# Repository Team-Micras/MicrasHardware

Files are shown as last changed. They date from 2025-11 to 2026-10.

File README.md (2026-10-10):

# Micras chassis

A parametric chassis for the Micras micromouse, written as [build123d](https://github.com/gumyr/build123d) code. Every dimension lives in `micras/params.py` and in the `*Params` dataclasses at the top of each part module. Change a value, then rerun the checks and the exports.

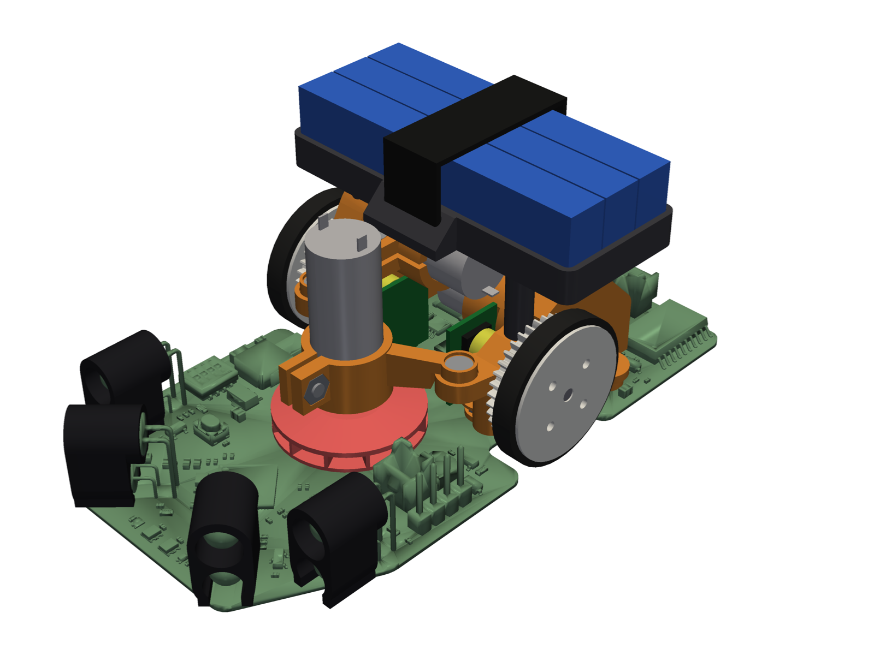
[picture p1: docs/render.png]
The robot: main board, sensor caps, fan, drive blocks, wheels and battery basket


The previous design (SolidWorks parts and assembly) was removed from the tree; it is in the git history (`git show 1307880:MicrasAssembly.STEP`).

## Workflow

```sh
uv sync                                   # Python 3.12 environment
uv run tools/export_board.py              # re-import the board after it changes in ../hw_debug (needs Windows KiCad); the wall sensors get the datasheet LED models of micras/leds.py (--original-sensors keeps the embedded model)
uv run pytest -q                          # design rules: clashes, board contact zones, LED fit, CoM over the axle
uv run tools/show.py                      # send the model to the OCP CAD Viewer, grouped, with the real board and its silkscreen (--simple: boxes)
uv run tools/render.py out.png --view iso --extra micras.assembly:printed          # the README's render (docs/render.png)
uv run tools/render.py out.png --dir=0.5,1,0.75 --focus=-5,13,14 --zoom 3 --extra micras.assembly:printed \
    --hide cell,velcro,sensor_cap --ghost block,fan_mount,basket,wheel,magnet_cup,impeller,tire   # docs/render_inside.png
uv run tools/export.py                    # build/print/<group>/*.stl (turned to print), build/print/parts.md, build/micras.step, build/skirt.dxf|svg, build/skirt_sheet.svg|pdf|png
uv run python -m micras.skirt             # the skirt files alone (seconds): build/skirt.dxf|svg and the cutting sheet
uv run tools/slice.py [plate ...]         # build/sliced/*.pm4n (Photon Mono 4) and *.gcode (Ender 3 V3 SE); see docs/printing.md
uv run tools/mass_report.py               # mass, centre of mass, yaw inertia, battery position for balance
uv run tools/battery_study.py             # compare battery arrangements
uv run tools/check_gears.py [--png f]    # the printed wheel with the brass pinion (the robot), and the all-printed pair: mesh through a tooth pitch, backlash, binding distance, tooth stress
uv run tools/fea.py [part ...] [--png]    # structural check of the printed parts (about 13 min for all, 1-3 min per part)
```

Run heavy jobs through `tools/capped.sh`, for example `tools/capped.sh uv run tools/export.py`. It caps memory at 6 GB so that a runaway job gets killed instead of crashing WSL.

**Structural check.** `tools/fea.py` meshes each printed part with gmsh and solves linear elasticity with scikit-fem (quadratic tets, pyamg solver) under rough worst-case loads: a 1 m/s crash into a wall (100 g), a 30 cm drop onto the wheels (300 g), side hits, handling pushes and the impeller's spin. It reports the stress exceeded in only 0.1 % of the volume (the raw peak sits in sharp corners, where linear FEA does not converge) against printed-material strengths (resin 35 MPa; PLA 37 MPa along its layers and 15 MPa across them, using the print orientation; TPU 8.6 MPa), and flags anything under a safety factor of 2 (3 for sustained loads). A flag means "look here": the loads are estimates. It runs on the CPU (about 5 GB at most); run it through `tools/capped.sh` with `MEM=5G`. `--dry` only meshes the parts and checks that every support and load finds its faces (seconds).

**Robot frame.** The same frame as the firmware: the origin is on the floor under the midpoint of the wheel axle, x points forward, y points left and z points up, in millimetres.

## Parts

| Module | Parts | Material |
|---|---|---|
| `drive.py` | bearing blocks (base + cap per side, or one piece) with the outer bearing's tube, magnet cups, wheels (gear, drum and end web in one piece) | resin |
| `fan.py` | closed radial impeller (Ø22, eye 10, 12 blades, neck into the board hole); the fan mount, a yoke hung from the drive caps with a split collar clamp | resin |
| `frame.py` | battery basket on two posts onto the drive caps, held shut by a velcro strap | PLA |
| `leds.py` | SFH 4550 and TPS601A models from their datasheets (they replace the board model's hand-drawn LEDs) and the numbers the caps are built from | – |
| `gears.py` | printed gears (0.5M 7T pinion, the 36T gear of the wheel), generated with py_gearworks; the robot uses the wheel gear with the brass pinion (`Gears.wheel_gear = "printed"`) | resin |
| `gear_guide.py` | drill guide for the brass 36T (the alternative): its bore opened to Ø7.8 and three Ø2.2 holes on Ø12.3 | resin |
| `trials.py` | trial parts on a plate of their own (`build/print/trials`), the default design untouched: impellers for a fan motor with a plain Ø1.5 shaft (bores 1.55 and 1.58, one or two dots), the tire cutting guide (a post and a turning ring with a blade slit at the channel's width), and wheel pairs with 0.20, 0.16, 0.12 and 0.08 mm of backlash with the brass pinion (the value engraved on the gear's inboard face, in hundredths) | resin |
| `front.py` | four wall-sensor caps that stand on the footprint outlines and set the LEDs' aim | black PLA |
| `skirt.py`, `skirt_sheet.py` | skirt and nose doubler patterns, and a 1:1 cutting sheet with rulers and a bank-card outline to trace them from a screen | film: 10 µm polyethylene, 40 µm cellulose acetate or TPU, chosen by measured downforce |
| `skirt_guide.py` | the skirt's cutting templates (a ring and a nose piece in the skirt's and the doubler's shapes: the scalpel runs along their walls) and its placing jig (an island under the band, a fence at the lip's edge, two pins in the board's screw holes) | resin |
| `fasteners.py` | the M2 screws, nuts and inserts in place, from the same helpers that cut their holes (viewer, STEP, `check_layout.py`) | bought |
| `skids.py` | where the two PTFE skates go under the board's centre line, front and rear, and their size | bought (mouse skates) |

`build/parts.md` lists each part's mass and print orientation. The printed parts come to about 16 g, and the whole robot to about 79 g with its fasteners (`mass_report.py`).

## Components

The bought parts the chassis is drawn around (in `micras/params.py`, measured where noted):

| Part | Size |
|---|---|
| Drive motors (2) | coreless 1020: can Ø10 ± 0.05 × 20 ± 0.2, shaft Ø1 × 6 ± 0.3, two solder tabs 1.5 × 0.32 at 7.4 pitch on the rear face (datasheet) |
| Fan motor | Ø9.97 × 23.08 (measured), 54k rpm at 7.6 V, with a pressed-on 9T module 0.3 pinion (tip Ø3.3, 4.6 long) that stays on |
| Batteries | 3 cells, 47.16 × 11.32 × 6.45 (51 long with their leads) |
| Magnets | Ø4 × 2 (the default) or Ø6 × 2, diametrically magnetised |
| Axles | Ø2 |
| Bearings | 2 × 5 × 2.5 (measured 2.57 wide) |
| Tires | 16 inside, 2 thick, 10 long as bought: stretched onto the wheel and cut to the channel (3.2) |
| Gears | brass 0.5M 7T pinion (0.98 bore), pressed on each motor shaft flush with its end; the 36T is printed as part of the wheel (the bought brass 36T, a plain 2 mm disc with a 1.98 bore, is the alternative: drilled in the printed guide, bore to Ø7.8 and three Ø2.2 holes countersunk on Ø12.3, and screwed to a wheel without teeth) |
| Screws | M2 × 5 countersunk |
| Threaded inserts | M2, 2 long, OD 3.2 (glued) |
| Nuts | M2 |
| Velcro strap | 10 wide |

## Key design decisions

- **Board contact.** Only the two L-shaped silkscreen zones carry the bearing blocks, with two countersunk M2 screws per side from below the board. Only a few other parts touch the board: the sensor caps on the casing outlines their footprints draw, and the skates stuck under it. The fan mount hangs from the drive caps and never touches the board. `check_layout.py` enforces this.
- **Encoder alignment.** The axle sits 9.00 mm above the board top, so it lines up with the AS5047U. The magnet is a Ø4×2 (the owner's default; `magnet_cup6` is the alternative cup for a Ø6×2, and the blocks' room fits either), 0.5 mm from the package face. A Ø6×2 there gives about 60 mT for N35 and 66 mT for N42 at the Hall elements when centred; the chip's window is 35–70 mT, so with an N42 magnet it must stay centred (0.3 mm off-centre adds about 20 mT). The Ø4×2 gives more field, not less (the Hall circle is near its rim): about 103–113 mT at 0.5 mm, over the window, so check the encoder's field-strength readings; at 1.3 mm it would give 54 mT N35, 59 mT N42 (`Magnet.gap = 1.3`: everything outboard moves out with it, which narrows the tire channel from 3.5 to about 2.7 mm).
- **Gears** (the default, `Gears.wheel_gear = "printed"`). The motors carry the bought brass 7T pinions, pressed on flush with the shaft end, and each wheel has its own printed 36T gear (part of the wheel). Round 7 ran this and the drilled brass 36T, and the printed one was preferred. `gears.py` makes a printable pair with the brass gears' module, tooth counts, widths and centre distance. A standard 7-tooth pinion would be deeply undercut, so the pair is profile shifted (+0.45 pinion, −0.45 wheel: the centre distance stays 10.75) and the pinion's tip is cut back 0.2 module (about 0.22 mm tip land, contact ratio 1.25). They are generated with [py_gearworks](https://github.com/GarryBGoode/py_gearworks) (Apache-2.0, build123d-native: true involutes with the generated undercut, profile shift, backlash, fillets; bd_warehouse's gears have no profile shift). 0.12 mm of backlash, most of it on the wheel's wider teeth; a print error may close the centre distance by about 0.15–0.19 mm before the teeth bind (`check_gears.py`). Round 6 had 0.06 mm: both pairs printed with no play left and the left one felt heavy on every tooth, so the print fattens the teeth by about 0.06–0.09 mm in the mesh. The robot runs the printed wheel gear with the brass pinion: about 0.25 mm of backlash (the wheel's −0.45 shift isn't made up by the unshifted pinion; `check_gears.py`). The printed pinions are no longer made.
- **Brass 36T** (the alternative: `Gears.wheel_gear = "brass"`; `build/print/alternatives/wheel_brass_gear_*` and `drill_guide_*`). The bought 36T (a plain 2 mm disc) is screwed to a printed wheel without teeth, so the rest of the drive stays as it is: its bore is drilled out to Ø7.8 (the wheel's hole: 0.3 mm round the bearing tube) and three Ø2.2 holes on a Ø12.3 circle, halfway between the bore and the tooth roots (Ø16.75), are countersunk 90° on its inboard face for M2×5 flat heads. The heads sit flush, because that face runs 0.25 mm from the block (0.24 mm of brass is left between a Ø4 countersink and the bore or the roots). The screws pass the wheel's web snugly (Ø2.1), so with the countersunk heads they centre the gear, and go into M2 nuts in hex pockets that open on the wheel's outer face. Each pocket is in a column inside the hollow drum, from the end web to the gear, and the three column ends are all the gear sits on. `gear_guide.py` is the printed drill guide, square outside so it clamps in a vise: a base whose pocket has the gear's outline (0.1 mm clear of its teeth: it centres the gear and keeps it from turning), and a square lid with the drill holes that drops into a square recess above it (it can't turn either), so the holes and the bore come out concentric with the teeth and the three holes evenly spaced.

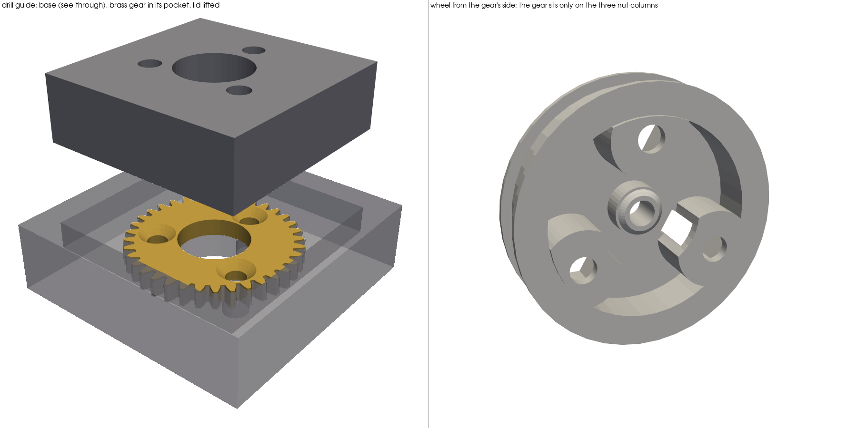
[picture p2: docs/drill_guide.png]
The drill guide (base see-through, the drilled gear in its pocket, the lid lifted off) and the wheel from the gear's side, with its three nut columns

- **Bearing blocks.** Each side is one solid block, like the v1 bearing blocks: an outer plate next to the gear, whose outline is the hull of the bearing housing, the motor seat, the two cap-screw bosses and (on the left) the frame boss, with the housing and the seat running inboard from it; the frame boss is blended into the motor seat's ring. Each cap has an ear in front of its front screw for the fan mount's arm, with an M2 nut trapped underneath and a recess that the arm's tab drops into (it places the mount before its screws go in), and sockets for the basket's pegs. Shallow pockets on the plate's hidden inboard face save a little resin without adding supports. It is split at the axle plane into base and cap. The motor rings have a 1.5 mm wall (they were drawn for the old eccentric sleeves, 2.1–2.7 mm round the motor, and the raised ring set the battery's height: it now sits 1 mm lower) and run inboard to 1 mm short of the centre line, gripping 14 mm of the motor's 20 (7.4 before), each with a slot open below that straddles its encoder daughterboard; they clear the other side's motor by about 0.45 mm. The motor's front face stops on a 1 mm flat ledge at the bore's outer end, then a 50° cone narrows to the pinion's clearance (a fully flat end would be a 2.3 mm ceiling inside the bore as it prints).
- **Two drive variants.** The default (the owner's choice after round 6) is the one-piece blocks, `Layout.blocks = "solid"`: the inner bearing presses in from the inboard end up to the lip, and both motor rings are slit clamps with an M2 screw (the left one on its rear side). `Layout.blocks = "split"` gives the base + cap blocks described above. The blocks' tops are the same in both, so the basket and the fan mount fit either. `tools/export.py` writes both (`build/print/drive_<solid|split>/`); print one. The motor's fit is set per seat: `ring_motor_fit_split` (`_upper` for the raised right motor), `ring_motor_fit_solid`.
- **Print files.** `tools/export.py` turns every part to its print orientation (`assembly.PRINT`: bores vertical, supports on hidden faces) and `tools/slice.py` slices the plates headless with PrusaSlicer and UVtools, for the Photon Mono 4 (Anycubic ABS-Like Pro 2 resin) and the Ender 3 V3 SE (PLA). A calibration print (`fit_test.py`) holds every fit at a range of clearances. See [docs/printing.md](docs/printing.md).
- **Skids.** The robot stands on one axle with its centre of mass over it, so the body tips about the axle onto whatever is lowest ahead or behind each time the acceleration changes sign. Two PTFE mouse skates (0.7 mm, cut to 10 × 7 mm ovals) stuck under the board's centre line, 45 mm ahead of the axle and 26 mm behind it, are those lowest points. The board rides 1.2 mm above the floor (Ø22.48 wheels), so their faces sit 0.5 mm up with the tires unloaded; the Shore 20 tires sink about 0.35–0.5 mm under the weight plus the fan's 4 N, so with the fan on the skates run 0–0.15 mm clear, and the body can only tip a fraction of a degree before it lands on PTFE, not on the board edge. They stay off the skirt's taped band, which holds the margin that seals the gap. The fan's suction acts on the whole skirted area, which is centred 7.4 mm ahead of the axle (not at the fan hole), so with the fan on, the nose rests on the front skate (about 0.65 N) unless the robot accelerates harder than about 20 m/s². Nothing else comes near the floor when the robot tips onto either skate (`check_layout.py` FLOOR). There is no bumper: the skirt's margin runs all the way round the nose, and the diagonal sensor caps are the robot's front corners.
- **Axial stack.** Along each axle: the magnet cup, whose sleeve runs along the axle inside a room in the housing; the housing shoulder; the inner bearing; the housing lip (the block's outer face); then a tube, one piece with the base (a full ring, not split), that reaches out through the wheel's gear into the wheel's hollow drum and holds the outer bearing at its end; and the wheel, one piece (gear, drum with the tire's channel, end web), turning round the tube and glued to the axle at its end web. The bearings sit about 4.4 mm apart, so the overhung wheel is held more stiffly than with the two bearings side by side; the wheel's axle boss runs from its end web in to just past the tube's end, gripping 2.9 mm of the axle so the wheel stays square to it; and the magnet cup's sleeve is 3.4 mm long (it glues the cup to the axle). Cones on the cup and the end web bear on the inner races only: the cup pushes the inner bearing out against the lip, the end web pushes the outer bearing in against the tube's step, so the axle is held both ways and the magnet cannot be pushed into the chip. The pockets are 0.1 mm longer than the bearings (they measure 2.57, not the nominal 2.5).
- **Backlash.** The motors sit straight in their rings, so the backlash is what the print gives; `Gears.center_adjust` tunes the center distance. The eccentric sleeves (±0.3 mm of adjustment) were dropped so the rings could be thinner and the battery lower; they are in the git history.
- **Battery.** Three cells on edge, one behind the other, in an open PLA basket on two posts screwed to the drive caps' frame bosses. Its walls are 4 mm tall: they only locate the cells. A velcro strap runs over the pack front to back, down outside the walls and through a slot in a lug on the foot of the front and rear walls, and closes on itself on top, so swapping the pack takes no tools (`FrameParams.wall_h = None` gives full-height walls with two straps through windows instead). Two posts in a line across the robot would let the basket pitch in a crash, so three feet under the floor rest on the drive caps (two on the left cap, one on the right cap's motor ring), each shaped to the cap's top; the two on the left carry pegs that drop into sockets in the cap, so the basket sits in place before its screws go in. The floor is ribs with solid bands under the posts and along all four walls, and the left post flares into it (`fea.py`: 100 g crash, 100 g side crash, 300 g drop, the strap's pull). Pull the strap snug, not hard: at 5 N each side the floor next to the right post sees 7 MPa across its layers (fine short term, but printed plastic creeps; 3 N keeps it at 4 MPa; computed for PETG, PLA is a little stronger). It prints upside down, its floor on supports from the bed (the bridges alone sagged; the lugs are 45° wedges). The box is sized for cells 51 mm long with their leads (the bodies are 47.16). The edge and pyramid arrangements have the same yaw inertia; edge is 2 mm lower (`battery_study.py`). `Battery.x` puts the center of mass over the axle (`mass_report.py`).
- **Motor layout.** Both motors sit behind the axle. Moving the raised motor in front of the axle was evaluated: it lowers the pack by about 10 mm but pushes the battery 4 mm further back and raises yaw inertia by 5.5 %.
- **No car body.** An earlier version had a one-piece PETG body (battery box with a lid, a faceted nose over the fan motor, fin and rear wing) whose airbox clamped the fan motor. The open layout is about 3.5 g lighter and simpler to print and service; the car body is kept at the git tag `car-body`.
- **Wall sensors.** The SFH 4550 emitter (5 mm epoxy, ±3°) and TPS601A receiver (a TO-18 metal can with a lens and a key tab, ±10°) are modelled from their datasheets in `leds.py`; the board's own sensor model had hand-drawn LEDs, with a receiver copied from the emitter. Their beams are already narrow, so aiming them matters far more than shaping the beams: a 1.5° pitch error changes the reading by 10–40 % up close, while an aperture in front of the lenses only cuts the signal (a Ø3 aperture loses about 70 %). Each cap (black PLA on the Ender; the painted resin ones did not work, docs/printing.md) stands on the casing outline the footprint draws, and fixes the LEDs' height and pitch from the board. Crush ribs grip each LED at its flange and body (each bore sized for its own part), its base lines up on the footprint's outline (a fork around the legs, behind the receiver, would block the slide-on; `check_sensors.py` sweeps the LEDs' path), a short keyway at the back of the receiver's sleeve takes its flange tab (which fixes its roll; the tab is only on the flange, so the keyway stops just past it), and the front stays open at full lens width behind a 1 mm hood. `FrontParams.emitter_tilt` pitches the emitter towards the receiver: an optics model predicts 15–50 % more signal at 10–40 mm for 1–2°; on the bench the 2° test cap worked well, so the caps are pitched 2°. In resin 0.10 mm crush ribs gripped best; in PLA the bores have more room (0.25 mm) and the ribs 0.05 mm until the FDM test caps choose (0, 0.05 or 0.10). The sensors can't see a wall closer than about 8 mm from the caps whatever the cap does, because the emitter sits 6.5 mm above the receiver.
- **Fan.** The fan motor (Ø9.97 × 23.08, 54k rpm at 7.6 V) would spin about 87k rpm with no load at 12.3 V, so it is limited by its power and heat, not its speed (docs/fan_study.md). A Ø22 closed impeller (eye 10, channel tapering 3 to 2 mm, twelve straight radial blades from hub to tip) makes 4 N with the skirt at about 46k rpm and 2.5 W from the battery by the CFD (docs/fan_study.md; the simpler 1D model said 42.6k rpm). The CFD found the curved-inlet variant no better and the backward-curved one worse, so the radial one is the default (`FanParams.style`) and the only one in the robot print; the other two are in `build/print/alternatives/` to compare on the bench. Never run it at full voltage (79k rpm, 17 W, overheats in minutes): cap it near 7.5 V and ramp it up over 0.2 s. Two things matter more than the impeller: the fan PWM's ripple (at 100 kHz a coreless winding of about 8 µH carries about 1.1 A rms of ripple, so run TIM12 at 300–400 kHz or add a 22–47 µH inductor) and the skirt closed round the wheel notches. The impeller's hub is glued onto the motor's 9T pinion (it doesn't come off). Its front shroud runs 0.3 mm above the clean Ø27 ring (the inlet seal) and a short neck dips into the board hole; seal the skirt well and tape over the encoder slots. The fan mount is a yoke: the motor sits in a collar, clamped by a split at its top with a crosswise M2 screw into a trapped nut; two arms reach back to the ears on the drive caps (a screw into a trapped nut each). It doesn't touch the board.

## Fasteners (M2×5 countersunk, M2×2 inserts, M2 nuts)

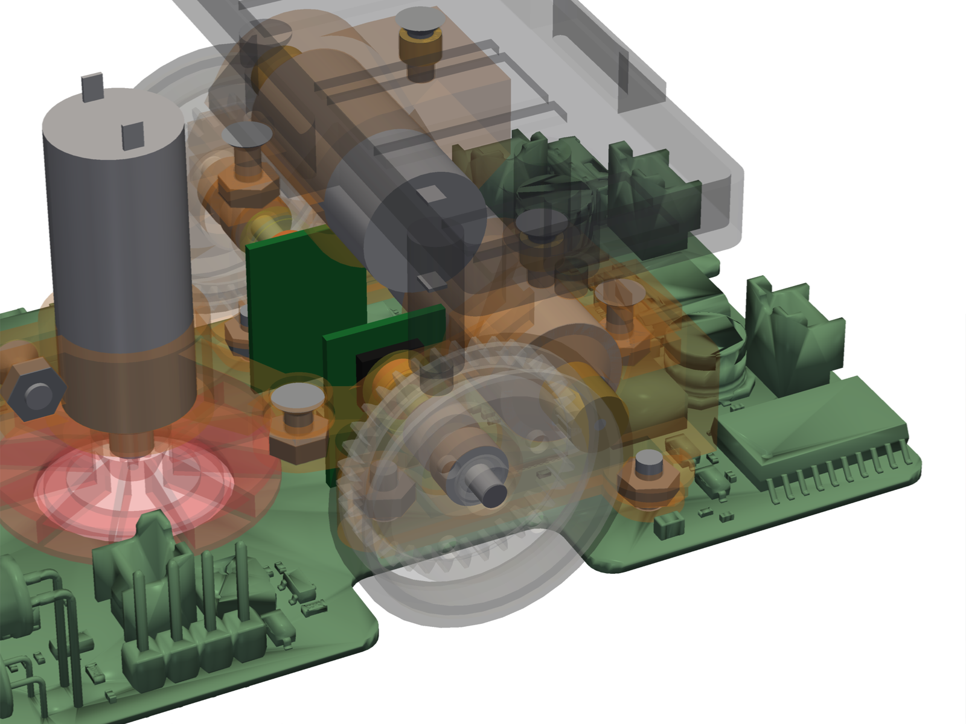
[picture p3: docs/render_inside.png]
Left drive side with the printed parts see-through: the board screws' nuts, the ring clamps, the fan mount's screws and nuts, the fan clamp, the bearings on the axle


11 screws, 2 inserts and 9 nuts in total with the default one-piece blocks and printed wheel gears (the split blocks: 14 screws, 6 inserts and 8 nuts, with the four cap screws but no clamp on the left ring; the brass 36T adds six screws and six nuts on the wheels). Each head seat is placed so the 5 mm screw engages the full 2 mm of its insert, or a whole nut. `fasteners.py` places every one, and `check_layout.py` checks that none of them runs into a part (a screw too long for its hole, a nut against a bearing).

| Joint | Qty | Insert in | Notes |
|---|---|---|---|
| board → bearing-block bases | 4 | M2 nut slid into a slot beside each screw hole, 0.9 mm above the board (as in the v1 blocks) | from under the board, heads in the board's countersinks |
| caps → bases (split blocks only) | 4 | bases (resin, glued) | heads counterbored into the cap bosses |
| right motor ring clamp | 1 | M2 nut trapped under the lower clamp ear | locks the right motor |
| left motor ring clamp (one-piece blocks, the default) | 1 | M2 nut trapped under the lower clamp ear | on the ring's rear side |
| brass 36T → wheel (the alternative gear only) | 6 (3 a side) | M2 nut in a hex pocket in the wheel's outer face | M2×5 countersunk, heads flush in the gear's inboard face |
| basket → caps | 2 | cap bosses (resin, glued) | left one down the post, through the basket floor |
| fan mount → caps | 2 | M2 nut trapped under each cap's ear | down through the arm's tab |
| fan motor clamp | 1 | M2 nut trapped in the clamp ear | crosswise through the split collar |

No screw holds these; they're pressed, glued or clamped instead:
- brass pinions on the motor shafts: pressed (as bought)
- magnets: glued in their cups; the cups and the wheels: glued to the axles
- outer bearings: pressed into the tubes
- tires: stretched into the wheels' channels (a flange each side), no glue
- impeller: pressed onto the shaft and glued
- sensor caps: crush ribs on the LEDs, a drop of glue on the base
- skates: their own adhesive, under the board
- cells: a velcro strap

## Assembly

1. **Board.** Trim the THT leads flush on the underside: the board is only 1 mm off the floor. Then the skirt, with the printed guides (`build/print/skirt_guide/`; stiff films such as acetate use the `_trim` templates in `skirt_guide_trim/`, whose lip ends 1.5 mm past the board edge so it just reaches the floor):
   1. **Cut.** Tape the film flat to a cutting mat by its corners. Lay `skirt_ring` on it, its smooth face down (the one without support marks), and hold it down with spread fingers; run a fresh #11 scalpel round its outer wall, then round its inner wall, upright with its flat against the wall (the walls stand 0.2 mm inside the lines, half the blade's thickness, so the cuts land on them). Cut the doubler from another piece with `skirt_nose`, its two end faces included. Without a printer, trace both from `build/skirt_sheet.pdf` instead: zoom the screen until its rulers and card outline match a real ruler and bank card.
   2. **Tape the board.** Lay 3 mm strips of transfer tape round the underside along the edge (polyethylene needs an LSE tape such as 3M 9472LE), trim them flush with the edge, rub them down and peel the liner.
   3. **Lay the film on `skirt_jig`**, turned so that it matches the island (the film has no top or bottom side): the doubler first, its band on the island's nose with a strip of tape on it, then the skirt, its band on the island (its inner edge on the island's inner edge) and its lip's edge at the fence (the outer step for the full lip, the inner one for the trimmed lip).
   4. **Press.** Lower the board onto the jig's two pins (its front-left and rear-right screw holes) until it sits on the band, and press it down all round the edge. Lift it straight off and burnish the band from below with a fingernail. The lip folds at the board edge: a soft film hangs down by itself, bend a stiff one down over the edge. It trails outward on the floor, round the wheel notches too.

   To replace the skirt later, unplug the motors, the fan and the battery and take the drive off with its four board screws (the pins use their holes); the sensor caps can stay on, and so can the skates if they sit clear of the band (the island stands 0.2 mm from them).
2. **Inserts and nuts.** Glue an M2 insert into each block's frame boss with CA or epoxy (heat-setting does not work in resin). Put an M2 nut in the trap under each block's fan ear, one under each motor ring's clamp ear, and one in the fan mount's clamp ear.
3. **Bearings, axles and wheels**, each block off the board:
   1. cut each axle 13.9 mm long and deburr both ends (a file or fine sandpaper, a small chamfer): rough ends jam in the bores
   2. press the inner bearing in from the inboard end (through the cup's room) up to the lip, and the outer one into the end of the tube, up to the step inside
   3. glue the magnet into its cup (pole direction as the encoder wants it) and slide the cup into its room, its sleeve towards the bearing
   4. put a drop of epoxy (or slow CA) on the axle's tip and push it in from outside, through the outer bearing and the inner bearing, into the cup until it stops on the magnet
   5. only with the brass 36T (`wheel_brass_gear_*`): drill the gear in the guide (`drill_guide_base` and `_lid`): drop the gear into the base's pocket (its teeth into the pocket's teeth), the lid into the square recess on top of it, and clamp the stack in a vise under a drill press, the jaws on the base's sides and the lid held down. Drill the three Ø2.2 holes, then open the bore with drills of growing size (2.5, 4, 6, 7.8: each follows the hole before), only the last one guided by the lid. Deburr, and countersink the three holes 90° on one face until an M2 flat head sits flush or just below: that face goes inboard. Drop an M2 nut into each pocket in the wheel's outer face, lay the gear on the wheel's web, its countersunk face away from the wheel, and screw it on with three M2×5
   6. push the wheel onto its axle, over the tube, until its cone touches the outer bearing, and glue it there (hold the axle's inner end, not the block, so the force doesn't go through the balls); the cones then hold the axle both ways with no end play
   7. stretch the tire (cut to the channel's width, 3.2 mm) over the wheel's outer flange into its channel
4. **Left block.** The encoder daughterboards go into the board first: each motor ring straddles one in a slot open below. Slide an M2 nut into the slot beside each of the block's two board-screw holes (flats along the slot, until it drops over the hole), then screw the block to the board from below with M2×5 countersunk screws through the board's countersunk holes.
5. **Left motor.** The brass pinion sits flush with the shaft end. Slide the motor into the left ring from the inboard side until its front face stops on the ledge at the ring's outer end, and tighten the clamp screw (it's under the basket: tighten it before the basket goes on). Check the wheel turns with a little play at the gears.
6. **Right block and motor.** The same on the right: the block after the left one (the motors cross over the middle; the right motor's rear end lies over the left ring), then its motor, then its clamp.

   With the split blocks (`Layout.blocks = "split"`), glue inserts into the bases for the cap screws too, and screw the bases to the board first. Lay the cup, the inner bearing (in its half-pocket, against the cup's cone) and the axle in the base, as above. Lay the left motor in its base seat against the ledge and fit the left cap with two M2×5, before the right cap. Slide the right motor into the right cap's ring and tighten its clamp, then fit the cap. Then the wheels.
7. **Fan.** The impeller only works turning the way the arrow on its top points (counter-clockwise seen from the motor's side): run the motor on the bench first and swap its two leads if it turns the other way. The fan motor's 9T pinion stays on: the impeller's bore is shaped like the pinion; slide it on as far as it goes (3.8 mm), check it runs true, and wick in thin CA. Balance it: run the fan slowly, read the vibration on the robot's IMU at the rotation frequency, add a tiny drop of CA on the light side, repeat (aim for about 5 µm of imbalance). Put the motor into the fan mount collar, with its terminal tabs pointing left and right, and tighten the clamp screw. Lower the mount in: its tabs land on the blocks' ears (the caps' with split blocks); screw both tabs down.
8. **Sensor caps.** Each cap holds one LED pair: the emitter (the clear 5 mm LED) on top, the receiver (the metal can with a small tab on its rim) below.
   1. **Bend the legs first.** The caps assume the receiver's legs bend down 2.0 mm behind its flange and the emitter's 2.55 mm behind its flange, with the LEDs' axes 3.25 mm (receiver) and 9.75 mm (emitter) above the board, pointing straight along the sensor's look direction. Solder them that way.
   2. **Tape the emitter.** One wrap of electrical tape round the emitter's epoxy body, from the flange forward, not over the flange or the lens (the cap's emitter bore is 0.2 mm bigger for it: `FrontParams.emitter_tape`).
   3. **Fit the cap.** Hold it in front of the LEDs and slide it straight back along the look direction: the upper bore over the emitter, the lower over the receiver, with the slot in the lower bore lined up with the receiver's tab. Keep pushing until the bores stop on the LED flanges. Don't twist it on: that bends the legs.
   4. **Check the aim:** the cap's base should sit flat on the board (no gap under its front), lined up with the sensor's outline printed on the board, and the LEDs should look straight out of the cap. The cap has no fork round the legs (it would block the slide-on), so its sideways position and its yaw come from the LEDs and from this line-up.
   5. **Glue:** a drop of CA where the base meets the board, not on the LEDs. To remove it later, cut the glue with a blade.
9. **Basket.** Set it on the blocks: the two pegs drop into the left block's sockets. Screw it to both frame bosses (the left screw goes down its post).
10. **Battery.** Thread the velcro strap through the front and rear lugs. Put the cells in the basket and close the strap over the pack.
11. **Skids** (last, on the finished robot with the battery in, on a flat hard floor: a glass sheet or the maze). Cut two 10 × 7 mm ovals from the 0.7 mm mouse-skate sheet and round their edges with fine sandpaper. Stick them on, long side along the robot:
    - the front one centred, its front edge just behind the skirt's taped band at the nose (3.2 mm behind the board's front edge);
    - the rear one centred on the USB notch, its rear edge just ahead of the skirt's taped band.

    Run the fan at full speed and hold the tail down with a finger, so the robot tips back onto the rear skate. Then slide strips of printer paper (0.1 mm) under the front skate from the front, under the skirt's margin:
    - **one sheet doesn't pass:** the skates would take load off the tires. Sand them thinner.
    - **four sheets pass:** the robot rocks more than it needs to. Put a layer of thin tape (about 0.1 mm) under each skate.
    - **otherwise:** done.

    With the fan on and the robot left alone, the nose rests on the front skate, and the rear one is clear by about 0.6 times the gap you measured.

## Still to measure

These values are estimates in the parameters, and the design should be updated once they're measured:

- Motor front boss diameter and length.
- How far the solder tabs stick out behind the motor.
- Populated board mass, estimated at 15 g.
- The bearings' outer diameter (the split pockets were tight at 5.13; the fit bar `fit_BRG` in the calibration print checks it).
- Fits (2.5 s, docs/printing.md; check them on the parts, the fit bars if one is off; all are parameters): `bearing_fit`, `solid_bearing_fit`, `ring_motor_fit_split` (`_upper` for the raised right motor), `ring_motor_fit_solid` and `split_relief` (drive), `insert_d` (3.35 glued in resin), the nut traps' `nut_af`, `axle_fit`, the sensor caps' `rib_interf` and `slot_w` (and check on a real TPS601A which way its tab points: `Tps601a.tab_angle`, read from the datasheet's outline as up and towards pin 1).
- The impeller on the bench: the radial one (the default) for its downforce and current against the PWM duty (the scale method in docs/fan_study.md); the CFD comparison of the three styles is there too, and the other two print from `build/print/alternatives/` to compare.
- Real downforce, on a scale with the fan running (docs/fan_study.md predicts about 4 N at 6.3 V average), and for the fan motor: its winding inductance (scope across R31, the most important unknown), resistance, no-load current at 6, 9 and 12 V, and the can's temperature after a 5-minute run.

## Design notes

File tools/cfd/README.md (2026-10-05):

# Suction-fan CFD (OpenFOAM in docker)

Steady RANS (k-omega SST, MRF) of the Ø22 suction-fan impellers over the board hole, to get fan curves and shaft
torque for `tools/fan_study.py`. Results and discussion: `docs/fan_study.md`, section "CFD results".

OpenFOAM is not installed on the host. Everything runs in the official OpenCFD image, **OpenFOAM v2512**
(`opencfd/openfoam-default:latest`, pulled 2026-10-03; set `CFD_IMAGE` to pin another tag), started by `cfd.sh` with
hard limits (14 GB RAM, no swap, 16 CPUs; `CFD_MEM`, `CFD_CPUS` override). Run one case at a time: WSL dies if the
memory runs out.

## Files

| file | what |
| --- | --- |
| `make_case.py` | writes a case to `build/cfd/runs/<impeller>_<mesh>/` from `template/` and the exported STLs in `build/cfd/` (`impeller_*.stl`, `fan_mount.stl`, `fan_motor.stl`, `geometry.json`; made by `tools/export.py`, not here) |
| `template/` | the OpenFOAM dictionaries, with `@@KEY@@` placeholders |
| `cfd.sh` | host wrapper: `docker run` with limits, mounts `build/cfd` and this folder |
| `run_case.sh` | inside the container: `mesh`, `solve <Pa> <iterations>`, `yplus` |
| `queue.sh` | runs a list of `cfd.sh` (or `walk ...`) jobs one after another, detached (log `build/cfd/runs/queue.log`); refuses to start while another queue runs |
| `walk.sh` | steps one case up the flowing branch (`walk.sh <case> <iterations> <Pa> <Pa> ...`) and stops at the first stage that ends stalled |
| `post.py` | stage averages, convergence and mass-balance checks, plots (`convergence.png` in each case), and the fan-curve JSON for `tools/fan_study.py --cfd` |

## Model

- Domain (generated as a closed STL of revolution): a Ø40 x 1.2 plenum under the board (floor z 0, board underside
  z 1.2), fed through its rim (`inlet`) at a fixed total pressure equal to minus the suction; the Ø15 hole through the
  board; open air above the board top, Ø80 up to z 42 (`ambient`: total pressure 0 in, static 0 out). The impeller,
  the mount (collar, plate, arm) and the motor are cut out of it.
- Rotation: MRF zone (cylinder r < 11.5, z 1.25-7.3, plus r < 5.5 up to z 9.9 around the hub), +z axis
  (counter-clockwise seen from above), 42,600 rpm by default. Only axisymmetric stationary walls (board top and hole,
  plate underside) lie inside the zone (`nonRotatingPatches`).
- Air: incompressible, nu 1.5e-5 m^2/s, rho 1.2 (OpenFOAM's p is p/rho; the scripts convert).
- Mesh: snappyHexMesh on a uniform background `dx` (coarse 3.0, medium 2.4, fine 1.92 mm; ratio 1.25), impeller
  surface and passages at level 4 (dx/16), the face gap and the neck gap at level 5 (dx/32: 3.2 / 4 / 5 cells across
  the 0.3 mm gaps), no prism layers, Spalding wall function (any y+).
- Numerics: SIMPLEC (relaxation p 0.7, U k omega 0.7), linearUpwind for U, limitedLinear for k and omega.
- Monitors (every 5 iterations, `postProcessing/`): moment on the impeller about z (pressure + viscous), flow through
  the inlet and the ambient boundary, flow up through the neck and through the whole hole at z 1.8 (their
  difference is the seal leak coming back down the neck gap), probes, residuals; at write times y+ and lines across
  the gaps.

## Rerun

The study (docs/fan_study.md, "CFD results") ran these stages. Each one continues from the previous state of its case.

```sh
docker pull opencfd/openfoam-default:latest                        # once (about 1 GB)
for imp in radial inducer backward; do tools/capped.sh uv run tools/cfd/make_case.py --impeller $imp --mesh medium; done
tools/capped.sh uv run tools/cfd/make_case.py --impeller radial --mesh coarse   # mesh study
tools/capped.sh uv run tools/cfd/make_case.py --impeller radial --mesh fine

tools/cfd/queue.sh \
  "radial_medium mesh" "radial_medium solve 1000 1500" "radial_medium solve 800 800" "radial_medium solve 600 800" \
  "radial_medium solve 900 800" "radial_medium solve 1200 800" "radial_medium solve 400 800" \
  "radial_medium solve 650 800" "radial_medium solve 700 800" "radial_medium solve 750 800" \
  "radial_medium solve 800 800" "radial_medium solve 850 800" "walk radial_medium 600 900 950 1000"
# inducer_medium / backward_medium: mesh, 1000 (1500 it), 800, 600, 400, 700, 900 (800 it each), then back to the
# flowing branch with 600 (500 it) and up: 750, 800, 850 (700 it), then "walk <case> 600 900 950 1000"
# (backward: "walk backward_medium 500 600 700 775", its branch ends earlier)
# radial_coarse: mesh, 1000 (1500), 600 (800), 750 (700), 800 (700); radial_fine: mesh, 1000 (1800), 600 (1000)

tools/capped.sh uv run tools/cfd/post.py --curves medium           # tables, convergence.png per case,
                                                                    # build/cfd/results.json, curves_medium.json
tools/capped.sh uv run tools/fan_study.py --cfd build/cfd/curves_medium.json
```

Single stages by hand: `tools/cfd/cfd.sh <case> mesh`, `tools/cfd/cfd.sh <case> solve <Pa> <iterations>`,
`tools/cfd/cfd.sh <case> yplus`.

Two side cases were copied from converged states rather than generated:
- `radial_medium_55k`: the fan-law check. It is `radial_medium`'s processor directories at iteration 7900 (750 Pa,
  flowing), with `omega` in `constant/MRFProperties` and `rpm`/`omega` in `case.json` set to 55,000 rpm, and an
  empty `constant/p0Table.steps`. Then `solve 1250 800`.
- `radial_coarse_lam`: the model-form bracket. It is `radial_coarse` at iteration 2300 (600 Pa), with
  `simulationType laminar` and `k`/`omega` dropped from the residual and line monitors. Then `solve 600 800`,
  `solve 750 800`, `solve 800 700`.

Timing on the Core Ultra 7 155H (WSL2): 1.1 / 2.2 / 4.2 s per iteration on the coarse / medium / fine mesh (0.77M /
1.35M / 2.56M cells), 2.3 GB of RAM on medium and 4.4 GB on fine. A medium impeller with its whole curve takes about
6 h.

**Two branches.** Near shut-off these impellers have two steady RANS solutions: a *flowing* branch (the impeller
pumps through the eye) and a *stalled* branch (almost no eye flow; the seal leak runs back down the hole into the
cavity). Which one a stage lands on depends on where it starts, so walk the suction down from 1000 Pa (stalled
side), and back up from 400-600 Pa (flowing side) in steps of 50 Pa (larger steps stall early) to bracket the stall. `post.py` classifies each stage by its eye
flow (above 0.3 L/s: flowing) and drops stages that switched branch part-way (std or drift of the flow over 0.04 L/s).
It builds the curve from the flowing branch up to its highest suction plus the stalled branch above it; `tools/fan_study.py` interpolates linearly across the gap, i.e. as a time-mix of the two
states.

`make_case.py --rpm` and `--suction` change the defaults (42,600 rpm, 1000 Pa from `geometry.json`); `--np` the MPI
ranks (default 12; this laptop is memory-bandwidth bound, 8-16 ranks run at the same speed). Each stage appends a
step to `constant/p0Table` (inlet total pressure against the iteration count) and a line to `stages.txt`;
`post.py` averages each stage's last 400 iterations.

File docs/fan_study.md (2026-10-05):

# Fan study: the 54k rpm fan motor on 3S

This study replaces the earlier one, which sized the fan for the 18k rpm motor. It is a model, not a measurement:
`tools/capped.sh uv run tools/fan_study.py` reproduces every number here in about 30 s (`--quick` runs on a coarser
grid). The script needs only numpy and scipy, and reads the board outline from `ref/board_mech.json`.

## Summary

- **Impeller: Ø22, eye 10, 12 straight radial blades, channel 3.0 mm at the eye tapering to 2.0 at the tip.**
  The shroud seal (0.3 face gap, 0.3 neck gap) is unchanged. The impeller mounts on the pinion by a plain bore on
  the tip circle, glued, with at least 3 mm of engagement (about 4 mm preferred).
- **Run it at about 4 N, not at its limit.** About 6.3 V average (duty = 6.3 V / V_bat) gives about 1000 Pa of
  suction, 42.5k rpm, 0.46 A and 3.0 W from the battery. The winding sits at 60 °C after 5 minutes and 66 °C
  continuously.
- **The motor could give 7–8 N (5–9 N over the parameter ranges), but the robot can't use it.** At 4 N each tire
  already carries 5× its no-fan load and sinks about 0.35–0.5 mm. The body is only 1 mm off the floor. Traction
  then exceeds the drive motors' force above about 3 m/s.
- **Two conditions for those numbers. Each matters more than the impeller design:**
  1. **The PWM ripple.** The fan PWM runs at 100 kHz now. A coreless winding of about 8 µH and 0.6 Ω then carries
     about 1.1 A rms of ripple on top of 0.45 A mean, and the ripple heats the winding more than the load does.
     As is, the motor would reach 93 °C at 4 N, and the most it can give within 85 °C is about 2.8 N (0.9 N if
     L = 5 µH). The fix is 300–400 kHz on TIM12 (the STSPIN958 takes up to 500 kHz), or a 22–47 µH inductor in
     the motor lead.
  2. **The skirt must close round the wheel notches.** The present pattern leaves the 1 mm gap open along both
     notches (about 50 mm² of leak). That limits the fan to about 3.5 N at the thermal limit, and 4 N would take
     96 °C.
- **Never 100 % duty.** On 12.3 V the Ø22 impeller would reach 79k rpm (hoop safety factor 3.2), 14 N and 17 W,
  and the winding would pass 140 °C in 5 minutes.
- A smaller impeller is not better for downforce with this motor. Its no-load friction (1.3 W at 64k rpm) grows
  with speed, so a slower, larger impeller makes the same downforce a little cooler. The difference is small,
  though: at 4 N, Ø26.4 runs 4 °C cooler than Ø22, and both reach about 8 N at the thermal limit. Ø22 frees a
  2.2 mm ring round the fan, is 28 % lighter (less unbalance) and has more structural margin (safe to 71k rpm
  against 59k). Only if the PWM ripple can't be fixed is the Ø26.4 worth keeping (3.35 N against 2.84 N at the
  limit), re-bladed as below.

## 1. Motor model (at 12.3 V)

| quantity | value | basis |
| --- | --- | --- |
| Ke = Kt | 1.33 mV·s/rad = 1.33 mN·m/A (7180 rpm/V) | 54k rpm no-load at 7.6 V, less the no-load I·R |
| friction torque | 0.20 mN·m at 64k rpm (1.34 W) | 150 mA no-load at 9 V (owner) × Kt |
| friction model | 0.10 mN·m + 0.015 µN·m per rad/s (half Coulomb, half viscous at the 9 V point) | split assumed; an all-Coulomb split changes the results by about 3 % |
| winding R (25 °C) | **0.35–0.8 Ω, nominal 0.55** (+23 % at 85 °C) | datasheets scaled by Ke², below |
| winding L | 5–15 µH, nominal 8 (estimate) | Faulhaber 1024 SR scaled by Ke² gives 5 µH |
| driver + shunt + wires | 0.2 Ω | STSPIN958 0.165 Ω per FET with two halves in parallel, R31 50 mΩ |
| no-load at 12.3 V | about 87k rpm, with 2.2 W of friction | so never run the bare motor at full voltage for long |
| stall at 12.3 V | 12–22 A | the driver's 5 A limit (TOFF) takes over: ramp the duty up |
| loaded, 100 % duty, Ø22 | 79k rpm at 12.3 V, 72k at 11.1 V | |

**Resistance from similar motors** (each one's R scaled by (1.33 / its Ke)², since R ∝ turns² for the same
size):

| motor | nominal V, no-load | stated R | Ke (mV·s/rad) | R scaled to this motor |
| --- | --- | --- | --- | --- |
| RIC-1020DT-074400 | 7.4 V, 39.5k rpm | 0.83 Ω (7.4 V / 8.9 A stall) | 1.79 | 0.46 Ω |
| RIC-1020DT-037450 | 3.7 V, 45k rpm | 0.23 Ω (3.7 V / 16.4 A) | 0.79 | 0.61 Ω |
| NFP-D1020T-1437 | 7.4 V, 51.5k rpm | 0.5 Ω (15.7 A stall) | 1.37 | 0.47 Ω |
| Kegu 1020R-V3 / V2 | 7.4 V, 39.1k / 33.6k rpm | 1.4 / 1.8 Ω | 1.81 / 2.10 | 0.71 / 0.68 Ω |
| Faulhaber 1024 K 003 SR (10 × 24) | 3 V, 12.2k rpm | 1.36 Ω | 2.33 | 0.44 Ω |

This motor is 23 mm long, longer than the 10 × 20 parts, which favours the low end. Kegu's own table is
internally inconsistent (its stall currents don't match V/R), and the NFP figures come from a search snippet,
because the page refused the fetch.

**Sensitivity to R** (Ø22, sealed skirt, 400 kHz PWM):
- At the thermal limit: 8.9 / 7.7 / 6.7 / 4.9 N for R = 0.35 / 0.55 / 0.8 / 1.5 Ω.
- At a fixed 40k rpm (3.5 N): the current is 0.40–0.41 A for any R. The winding reaches 54 / 57 / 60 / 69 °C
  after 5 minutes.
- So R hardly matters at the recommended point. It matters at 100 kHz, where the ripple loss scales with R/L².

**Safe power.** The thermal model uses the Faulhaber 1024 SR values: winding to housing 16 K/W (6.5 s), housing
to air 41 K/W on a plastic flange (180 s), taken as 35 K/W for a moving robot. The winding may reach 85 °C (a
cheap motor's NdFeB magnets and bonded winding) in 30 °C air. The friction heat goes in on the housing side.

| loss the motor can take | 1 min | 3 min | 5 min | continuous |
| --- | --- | --- | --- | --- |
| all in the winding (I²R) | 2.1 W | 1.44 W | 1.24 W | 1.08 W |
| all friction | 5.5 W | 2.5 W | 1.9 W | 1.6 W |

A mixed load of about 1.4–1.6 W is the budget for bursts of a few minutes. That is about 0.8–1.0 A rms in a hot
0.68 Ω winding, once the friction (0.7–1.2 W at 40–60k rpm) is counted. This agrees with RIC's "rated" 1.0 A for
the 7.4 V 1020, which is meant for prop-cooled aircraft. Bursts of a few minutes are about one housing time
constant, so they gain little over continuous running: 5 minutes from cold allows about 15 % more than
continuous, 3 minutes about 30 %.

With the ripple fixed, the mechanical output at the limit is about 5.5 W at 59k rpm (Ø22) for 5-minute bursts,
4.2 W at 54k continuously. The textbook maximum, V²/4R ≈ 45 W, means nothing here.

The PWM ripple decides everything else. The bridge switches synchronously: in parallel mode PWM1 = 1 turns the
high sides on and PWM1 = 0 the low sides (DS14341 table 11), so the winding sees 12.3 V or 0. Ripple at 50 %
duty:

| | 100 kHz, 8 µH | 100 kHz, 5 µH | 400 kHz, 8 µH | 100 kHz + 47 µH |
| --- | --- | --- | --- | --- |
| ripple, rms | 1.09 A | 1.71 A | 0.28 A | 0.16 A |
| copper loss it adds | 0.8 W | 2.0 W | 0.05 W | 0.02 W |

**Measure L before relying on any of this.** With a scope across R31 at 50 % duty, ΔI_pp ≈ 12.3 V · 0.25 / (L · f).
At 400 kHz the result barely depends on L: 7.4 N at 5 µH against 7.7 N at 8 µH, both at the limit.

## 2. Impeller and operating point

### Model

The model is in `tools/fan_study.py`. The ranges below are its sensitivity runs.

- **Head.** Euler head with Wiesner slip (σ = 0.82 for 12 radial blades). The tip's kinetic energy is lost (no
  volute), and straight radial blades take a shock loss of 0.8 · ½ρu₁² at the eye. On top of that, a 3D factor
  κ = 0.9 (range 0.75–1.0). Shut-off suction comes out at 0.72–0.75 · ½ρu₂².
- **Power.** Shaft power is the Euler power on the through-flow, plus low-flow recirculation
  (0.03 · ρu₂³D₂b₂, range 0.015–0.06) and laminar disk friction.
- **Inlet seal.** The 0.3 mm face gap over the Ø27 ring and the 0.3 mm neck gap in the hole act as two thin
  annular orifices in series. They leak from the tip back to the hole, and the shroud's swirl opposes the leak a
  little. That leak is 0.3–0.5 L/s, two to three times the skirt's, so it is most of the impeller's flow.
- **Board.** The gap under the board is solved as 2D lubrication (Hele-Shaw) flow on a 0.5 mm grid, with the
  hole at the suction pressure. The gap is taken as 0.9 mm, the 1.0 mm less the tires' sink.
- **Skirt.** The bent-down film margin leaks like an effective contact gap δ over a 1 mm contact width (laminar
  plus orifice):

| case | δ | notches | leak at 1000 Pa | downforce / suction | centre of pressure |
| --- | --- | --- | --- | --- | --- |
| sealed, good floor | 0.02 mm | closed | 0.01 L/s | 3970 mm² | 7.8 mm ahead of the axle |
| **sealed, typical (design case)** | 0.05 mm | closed | 0.15 L/s | 3930 mm² | 7.9 mm |
| sealed, poor (joints, dust) | 0.10 mm | closed | 0.59 L/s | 3800 mm² | 8.3 mm |
| present pattern | 0.05 mm | open: 0.5 mm margin on the inner face, none on the end faces | 1.33 L/s | 3630 mm² | 9.5 mm |

With the skirt closed, the pressure under the board is uniform to within 1–5 %. The downforce is then just the
suction times the 3970 mm² footprint (board plus hole): 1 N per 254 Pa.

**The notches can be closed.** The 36T wheel gear's lowest point is 1.54 mm above the floor, which is above the
board's underside (1.0). The tire's inner face is at |y| = 21.0. At x = ±8.5 the tire is 4.0 mm off the floor. So
a 2 mm margin bent down along the notch's inner and end faces touches nothing. This change belongs to the skirt,
not the fan: drop the notch cut in `skirt.pattern` so the 2 mm margin runs all the way round, and let the FLOOR
check confirm it.

### Recommendation

**Ø22 closed impeller:**

| part | value |
| --- | --- |
| eye | 10 |
| hub and nose | Ø6 (over the pinion) |
| blades | 12 straight radial (β₁ = β₂ = 90°), 0.55 thick |
| channel | 3.0 at the eye, 2.0 at the tip (cone-shaped backplate) |
| shroud | 0.6, flat, 0.3 above the Ø27 ring |
| backplate | 0.8 |
| neck | as now (ID 13.4, wall 0.5, 0.3 radial gap in the Ø15 hole) |
| mass | about 0.85 g (1.18 g now) |

Sensitivities at the thermal limit, against 7.7 N nominal:

| change | downforce |
| --- | --- |
| channel at the tip 1.5 / 3.0 | 7.9 / 7.2 N |
| eye 9 / 11 | 7.8 / 7.5 N |
| 9 or 16 blades | ±0.1 % |
| seal gaps 0.2/0.2 | 8.4 N |
| seal gaps 0.4/0.3 | 7.5 N |
| twisted inducer at the eye (half the shock loss) | 8.3 N, not worth the printing trouble |

Keep the 0.3 mm neck gap. The mount is located by the drive caps, not by the board hole, so a tighter gap may
rub.

**Operating points** (Ø22, sealed typical skirt, 12.3 V, nominal motor):

| downforce | suction | rpm (u₂) | through-flow: skirt + seal | shaft | V avg (duty) | battery | mean I | Tw 5 min / cont., 400 kHz | Tw 5 min, 100 kHz now |
| --- | --- | --- | --- | --- | --- | --- | --- | --- | --- |
| 3 N | 763 Pa | 36.9k (42 m/s) | 0.12 + 0.29 L/s | 1.3 W | 5.5 V (44 %) | 2.1 W | 0.37 A | 54 / 58 °C | 86 °C |
| **4 N** | 1019 Pa | 42.6k (49 m/s) | 0.16 + 0.34 L/s | 2.0 W | **6.3 V (52 %)** | 3.0 W | 0.46 A | **60 / 66 °C** | 93 °C |
| 5 N | 1270 Pa | 47.6k (55 m/s) | 0.19 + 0.37 L/s | 2.8 W | 7.1 V (58 %) | 4.1 W | 0.55 A | 66 / 74 °C | 98 °C |
| limit, 5 min | 1958 Pa | 59.1k (68 m/s) | 0.27 + 0.46 L/s | 5.5 W | 9.0 V (73 %) | 7.3 W | 0.81 A | 85 °C | |
| limit, continuous | 1635 Pa | 54.0k | | 4.2 W | | | | 85 °C | |

The thermal limit is 7.7 N for 5-minute bursts and 6.4 N continuous. Over the ranges: 8.9 N at R = 0.35, 4.9 N at
R = 1.5, 6.7–8.4 N for κ = 0.75–1.0, 5.6 N with the poor skirt, 3.5 N with the present notches. At 4 N with the
notches open, the fan needs 49.6k rpm and 1.1 A, and the winding reaches 96 °C.

### PWM limit

**Yes, limit the fan with PWM, for traction and sink more than heat.**

- Command an average voltage, not a duty: duty = V_cmd / V_bat. The pack sags from 12.3 V to about 10.5 V under
  load, and the same duty would lose about 25 % of the downforce over a run. The fan has no tachometer, so this
  is open loop.
- V_cmd = 6.3 V for about 4 N. Calibrate it on the scale rig.
- Hard cap at about 7.5 V: 52k rpm, about 6 N.
- Ramp up over 0.2 s or more. Stall would draw 12–22 A, against the driver's 5 A limit.
- At 100 kHz, keep V_cmd at 5.5 V or below (about 3 N, 86 °C after 5 minutes) until the ripple is fixed.

### What more than 3–4 N means for an 87 g robot

The centre of pressure is 7.9 mm ahead of the axle, so the nose rests on the front skid (x = 45), which carries
F · 7.9/45 ≈ 18 % of the downforce. Tire sink is the firmware model's 4000–6000 N/m per tire, taken as linear.
Real rubber stiffens, so it is an upper bound.

| F | per tire (0.43 N without fan) | traction at μ = 1 | sink | drag: rolling (c_rr 0.03) + skid (μ 0.25) + skirt |
| --- | --- | --- | --- | --- |
| 2 N | 1.25 N | 2.5 N, 29 m/s² | 0.21–0.31 mm | 0.19 N |
| 4 N | 2.08 N | 4.2 N, 48 m/s² | 0.35–0.52 mm | 0.35 N |
| 6 N | 2.90 N | 5.8 N, 67 m/s² | 0.48–0.73 mm | 0.50 N |
| 8 N | 3.72 N | 7.5 N, 86 m/s² | 0.62–0.93 mm | 0.66 N |

The drive motors, at full 19.6 V, give 7.3 N stalled, 5.1 N at 2 m/s, 4.0 N at 3 m/s and 2.9 N at 4 m/s. So:

- **Beyond about 4 N, straight-line acceleration is motor-limited** above roughly 2.5–3 m/s. Only cornering and
  low-speed braking still gain.
- **Beyond about 5–6 N the 1 mm gap runs out.** The sink approaches the clearance, and the skids would take load
  off the tires, which is the opposite of what they are for.
- **Drag grows with downforce.** The front skid is the biggest share: a PTFE patch halves it.
- **The skid set needs recutting.** `skids.py` sizes the five-pad set for 0.13–0.23 mm of sink at 1 N. At 4 N the
  sink is 0.35–0.5 mm.
- **Odometry shifts.** The rolling radius drops by about 0.15 mm (77 µm/N per tire), so calibrate the wheel
  radius with the fan on.
- Board bending under 1000 Pa is about 0.01–0.03 mm: negligible.

## 3. Structure (Anycubic ABS-Like Pro 2)

Material properties from the TDS: UTS 35–45 MPa, flexural modulus 1.4–1.8 GPa, 35–40 % elongation, HDT
60–65 °C.

**Hoop stress.** The shroud and backplate are annular disks, and their peak stress is at the bore. The blades'
centrifugal load is added to them.

| | 42.6k rpm | 55k rpm | 70k rpm | 79k rpm (100 % duty) |
| --- | --- | --- | --- | --- |
| Ø22 | 3.1 MPa (SF 11) | 5.2 MPa (SF 6.7) | 8.4 MPa (SF 4.2) | 10.9 MPa (SF 3.2) |
| Ø26.4 | 3.8 MPa | 7.5 MPa (SF 4.7) | 12.2 MPa (SF 2.9) | |

The safe speed is taken at SF 4 on 35 MPa, which covers stress concentration of about 2 at blade roots and a
warm, possibly voided print. That gives **71k rpm for Ø22** and 59k for Ø26.4. Resin weakens near its HDT, so
hold more margin than that whenever the motor runs hot.

**Blades.**
- Straight radial blades take no centrifugal bending.
- The aerodynamic load is about 4 mN per blade at 4 N, which is negligible.
- A backward-curved blade would add plate bending, about 0.25 MPa · cos β per unit span at 55k rpm, still
  small. That is not a reason to curve them.

**Hub on the pinion.**
- A diametral interference of 0.03 mm in a Ø6 hub gives about 10 MPa hoop at the bore (Lamé, E = 1.6 GPa).
  Keep the interference at 0–0.03 and let glue do the rest.
- The glue (CA, about 5 MPa over about 34 mm²) carries about 0.2 N·m. That is 500 times the 0.45 mN·m running torque, and
  about 30 times the 6.7 mN·m the driver's 5 A limit can produce.
- The pinion runs next to a 60–85 °C motor, while the resin's HDT is 60–65 °C. Keep the motor near the
  recommended point (≤ 66 °C), and expect a press fit to relax, which is why the joint should be glued.

**Axial pull.** The suction pulls the impeller towards the board with about 0.25 N at 1000 Pa (0.5 N at
2000 Pa). This is like a small propeller's thrust on these motors. It takes up the rotor's axial play (typically
0.05–0.15 mm), so set the 0.3 mm shroud gap with the shaft pulled towards the board.

**Balance.** The force is m·e·ω². At 42.6k rpm (710 Hz), 0.85 g:

| eccentricity | rotating force | ISO 1940 grade |
| --- | --- | --- |
| 5 µm | 0.08 N | G22 |
| 10 µm | 0.17 N | G45 |
| 25 µm | 0.42 N | G110 |

At 25 µm the rotating force is half the robot's weight, and it lands at 710 Hz, where the IMU listens. Printed
and glued parts land around 10–30 µm, so balance it. The robot's own IMU can do it: run at the working speed,
read the acceleration amplitude and phase at the rotation frequency, add a trial drop of CA or paint (about 1 mg
at r = 10 corrects 10 µm) and repeat (one-plane trial-weight method). Or sand the shroud rim. Aim for 5 µm or
less.

## 4. Mounting on the 9T m0.3 pinion

The pinion: tip Ø3.30, pitch Ø2.70, root about Ø1.95, 4.6 mm long, pressed on the shaft.

- **Recommended: a plain bore on the tip circle, glued.**
  - The nine tips are ground concentric with the shaft, so they centre the impeller better than a printed spline
    could. The torque is tiny, so it needs no positive drive.
  - The impeller prints tilted 45°, so a printed bore comes out stepped and oval. Model it undersize (Ø3.15), then
    open it with a Ø3.2–3.3 drill in a pin vise. The bore should end up 0–0.03 mm under the tip diameter, so the
    tips bite slightly.
  - Then wick thin CA in.
  - Confirm the bite on a calibration row with bores 3.15 / 3.20 / 3.25 / 3.30, printed tilted like the impeller.
- **Engagement: at least 3 mm (L/D ≈ 1), about 4 mm preferred.** With 0.03 mm of clearance over 4 mm, the rim
  wobbles about ±0.08 mm axially.
  - Today's stack puts a 1.2 mm mount plate and a 0.4 mm gap between the motor face and the hub. That leaves only
    about 3.0 mm of a 4.6 mm pinion that starts at the face. Measure where the pinion starts.
  - To get about 4 mm, let the hub rise through the plate (plate hole ≥ hub Ø + 0.8), or drop the plate under
    the hub. The collar clamp already locates the motor.
  - Then end the hub 0.3–0.5 mm below the motor's front boss.
- **Bore end.** Make it blind, so air doesn't leak through the tooth spaces from the backplate side to the eye.
  End it 0.3 mm or more past the pinion's end, and keep 1 mm or more of nose wall around the bore all the way
  down. Today's cone narrows to 0.6 × hub radius at its tip, so the nose needs to be a Ø6 cylinder over the bore,
  then the cone.
- **Assembly.** Clamp the motor in the mount and stand the mount on a flat plate with the impeller under it,
  shroud down on 0.3 mm shims, and the shaft pulled out to the end of its play. Then wick the CA. The mount sets
  both the gap and the squareness.
- **Alternatives considered.**
  - An internal 9T spline (0.47 mm teeth): it can't be printed tilted to ±0.03, needs clearance anyway, and
    centres no better.
  - A loose bore filled with epoxy: no centring.
  - A two-piece impeller, with the backplate, blades and hub printed axis-vertical (round, concentric bore) and a
    flat shroud ring glued on, would give the best bore. It is worth it if balancing proves hard.

## 5. FanParams changes (micras/fan.py)

| parameter | now | recommended | note |
| --- | --- | --- | --- |
| `d2` | 26.4 | **22.0** | the rim ends 2.5 mm short of the nearest part (SOT-89 at 13.54) |
| `eye_d` | 11.0 | **10.0** | stays inside `neck_id` 13.4 |
| `h_tip` | 3.0 | **2.0** | `h_eye` stays 3.0 (cone-shaped backplate) |
| `hub_d` | 4.5 | **6.0** | 1.35 mm wall round the Ø3.3 pinion tips |
| `bore_d` | 0.9 | **3.15** | printed undersize; finish to 3.27–3.30, glued (section 4) |
| `hub_above`, `plate_gap`, `plate_t` (mount) | 1.5, 0.4, 1.2 | engage ≥ 3 mm (about 4) of the 4.6 mm pinion | the hub ends 0.3–0.5 below the motor face; the plate hole clears the hub, or the plate goes |
| nose (the code in `impeller()`) | cone from 0.6·rh | Ø6 cylinder over the bore, cone below | keep 1 mm or more of wall round the blind bore |

Unchanged: `blades` 12, `blade_t` 0.55, `blade_angle` 90, `h_eye` 3.0, `shroud_t` 0.6, `back_t` 0.8, `shroud_z`
0.3, `neck_id` 13.4, `neck_t` 0.5, `neck_l` 1.2, `nose_d` 6.0.

Outside FanParams:
- Skirt: margin round the notches, as in section 2.
- Skid set: recut for 0.35–0.5 mm of sink.
- Assembly notes (`assembly.PRINT`, `docs/printing.md`): the impeller bore is now Ø3.3 on the pinion, no longer
  reamed to 0.97.
- Firmware: these are recommendations only, nothing was edited.
  - TIM12 at 300–400 kHz (ARR 687 gives 400 kHz).
  - The fan command as an average voltage, about 6.3 V with a 7.5 V cap.
  - `fan_downforce` to be set from the scale measurement. 1.0 N is now an underestimate if the fan runs at
    6.3 V.

## Uncertainties and what to measure

- **Fan model.** The shut-off coefficient and losses are textbook correlations, not measured on this impeller:
  ±15 % on suction. The skirt's contact gap is a guess (0.02–0.1 mm). The 1000 Pa operating point should be
  confirmed on the scale rig, and the voltage adjusted to suit.
- **Motor.** Measure these, and the script takes them directly (`Motor(R=..., L=..., i0_meas=..., visc=...)`):
  - R, with a 4-wire measurement on a held rotor, averaged over a few positions.
  - L, with an LCR meter or from the ripple on R31.
  - The no-load current at 6, 9 and 12 V, which fixes the friction split. It often drops by 20–30 % after
    run-in.
  - The can temperature after a 5-minute run at the chosen voltage.
- **Thermal limits.** The thermal resistances are Faulhaber's, applied to a cheap motor, and its real limit may
  be lower than 85 °C. Brush wear at 40–60k rpm sets its life (likely tens of hours). Lower speed helps that too.
- **Tires.** The sink figures use a linear tire stiffness, so they are upper bounds.

## Sources

- Faulhaber DC-Micromotors Series 1024 … SR datasheet (R, kM, L, thermal resistances and time constants):
  https://www.faulhaber.com/fileadmin/Import/Media/EN_1024_SR_FMM.pdf
- RIC Motor RIC-1020DT table (no-load, rated and stall figures): https://www.ricmotor.com/details/1020-coreless-motor
- Kegu 1020R table: https://kegumotor.com/en/product/10mm-coreless-dc-motor-model-1020r-7-4v-dc-24500rpm.html
- NFP-D1020T-1437 (0.5 Ω, 51.5k rpm, 180 mA at 7.4 V; search summary only, the page refused the fetch):
  https://nfpshop.com/product/10mm-dc-motor-20-8mm-length-7-4v-dc-model-nfp-d1020t-1437-c
- ST STSPIN958 DS14341 (parallel-mode truth table, f_PWM ≤ 500 kHz, R_DS(on)): `../hw_debug/datasheets/stspin958_lcsc.pdf`.
  Board: R31 = 50 mΩ, motor between the tied OUTs and the sense node (`../hw_debug/kicad/Drivers.kicad_sch`).
  Firmware: TIM12 period 2749 at 275 MHz = 100 kHz (`../MicrasFirmware/cube/micras_v1.ioc`).
- Anycubic ABS-Like Resin Pro 2 TDS: https://get3d.pl/wp-content/uploads/2026/02/ABS_Like_Resin_Pro_2_TDS_EN.pdf
- Tire compliance and contact stiffness: `../MicrasFirmware/config/targets/v1/robot.hpp`, `sim/robot.toml`.
- Methods: Wiesner slip factor; Pfleiderer/Stepanoff shut-off head of impellers without a volute; free-disk
  friction C_M = 3.87/√Re (laminar); Hele-Shaw flow; Lamé thick cylinder; ISO 1940 balance grades.

## Update: curved blade inlets (after the study)

The study's model, run at 4 N, shows the outlet blade angle hardly matters this close to shut-off (60° and 30°
backward-curved outlets give the same result), but the inlet does: the air reaches the eye at about 24° from the
tangent, and straight radial blades meeting it edge-on cost about 0.3 W of shaft power. With the inlet shock loss
cut from 0.8 to 0.2 (`k_shock`; an estimate, the real gain may be anywhere from about 5 to 20 %):

| blades | rpm at 4 N | shaft | battery | winding, 5 min | max force (85 °C) |
| --- | --- | --- | --- | --- | --- |
| straight radial | 42.6k | 2.0 W | 3.0 W | 60 °C | 7.7 N |
| radial tip, curved inlet | 39.6k | 1.7 W | 2.6 W | 57 °C | 8.6 N |

So the impeller (micras/fan.py) keeps radial tips, which don't bend spinning, but its six main blades start inside
the eye at 26° and ease to radial by r = 8 mm, leaning into the turn; six straight radial splitters from r = 7 mm
keep 12 blades at the tip (12 curved inlets would block about 60 % of the eye). It only works one way round: the
arrow on its top shows the direction (counter-clockwise seen from the motor's side).

## Comparing the three impellers on the bench

`fan.impeller_variants()` makes three Ø22 impellers that differ only in their blades: A straight radial (12),
B curved inlets with splitters (6 + 6, the default), C backward-curved (7, 26° at the inlet to 35° at the tip,
like a vacuum-cleaner fan). Run each at the same PWM duty and compare downforce and current.

Measuring downforce: weighing the robot doesn't work (the suction pulls the robot down and the floor up by the same
amount). Lay a flat, stiff plate a little smaller than the board on the scale, rest the wheels on two blocks beside
it so the board sits at its height over the plate with the skirt touching it, tare, and run the fan: the plate is
pulled up, and the scale's drop is the downforce.

## CFD results (steady RANS of the three impellers)

The three Ø22 bench variants were run in OpenFOAM to check the 1D model above:
- A: straight radial, 12 blades;
- B: curved inlets with splitters, 6 + 6;
- C: backward-curved, 7 blades.

All three turn counter-clockwise seen from above, at 42,600 rpm. How to rerun: `tools/cfd/README.md`. The cases are
in `build/cfd/runs/` (not committed). The tables come from `build/cfd/post_report.txt`, and the fan curves are in
`build/cfd/curves_medium.json`.

**Setup.**
- **Solver.** OpenFOAM v2512 (docker `opencfd/openfoam-default`), steady `simpleFoam` (SIMPLEC), an MRF zone round
  the impeller, k-omega SST, incompressible air (ρ 1.2, ν 1.5e-5).
- **Domain.** A Ø40 × 1.2 cavity under the board, fed through its rim at a fixed total pressure (−suction). Then the
  Ø15 hole, and Ø80 × 40 of open air above the board. The mount (collar, plate, arm) and the motor are walls.
- **Seal.** The 0.3 mm face gap and neck gap get 3.2 / 4 / 5 cells across on the coarse / medium / fine meshes
  (0.77M / 1.35M / 2.56M cells). There are no prism layers and the wall function is Spalding's. y+ on the impeller
  averages 4–7, with a maximum of 18–29.
- **Measured.** The net flow drawn from the cavity (the useful flow), the flow up the neck (their difference is the
  seal leak coming back down the neck gap), and the shaft torque (the moment on the impeller about z, pressure plus
  viscous).
- **Stages.** Each suction is a stage of 500–1500 iterations, continuing from the previous one and averaged over its
  last 400.

### What the CFD shows

1. **Two branches near shut-off, with hysteresis.**
   - **Flowing branch.** The impeller pumps 0.5–1.1 L/s through the eye, and the seal leak is small: 0.06–0.16 L/s.
   - **Stalled branch.** Almost no eye flow. The seal leak (0.2–0.3 L/s) comes back down the hole with the shroud's
     swirl, and a vortex in the hole holds the eye about 300 Pa below the cavity. The net flow then runs *into* the
     cavity.
   - **Where it switches.** Stepping the suction up from the flowing side, A and B keep flowing up to 850 Pa and stall
     at 900 Pa. C keeps flowing to 775 Pa and stalls at 800 Pa. Coming down from 1000 Pa, all three stay stalled at
     800 Pa and recover by 600 Pa.
   - **Where the robot runs.** It needs only about 0.15 L/s of useful flow (the sealed skirt's leak). That is far
     below the lowest flow of the flowing branch (0.45–0.6 L/s), so the fan works in the stall gap.
2. **Less suction per rpm than the 1D model.** At 42.6k rpm, net flow from the cavity, in L/s:

   | suction | A, CFD | B, CFD | C, CFD | A, 1D | B, 1D | C, 1D |
   | --- | --- | --- | --- | --- | --- | --- |
   | 400 Pa | 1.12 | 1.12 | 0.89 | 2.28 | 2.57 | 1.69 |
   | 600 Pa | 0.99 | 0.94 | 0.74 | 1.81 | 2.15 | 1.34 |
   | 750 Pa | 0.86 | 0.72 | 0.53 | 1.39 | 1.80 | 1.05 |
   | 800 Pa | 0.69 (stalled from above: −0.13) | 0.66 (−0.12) | −0.10 (775 Pa: 0.47) | | | |
   | 850 Pa | 0.58 | 0.54 | −0.13 | 1.06 | 1.53 | 0.84 |
   | 900 Pa | −0.22 | −0.21 | −0.18 | | | |
   | 1000 Pa | −0.28 | −0.26 | −0.25 | 0.32 | 1.07 | 0.47 |
   | net-flow shut-off | 886 Pa | 886 Pa | 796 Pa | 1033 Pa | 1192 Pa | 1136 Pa |

   The CFD "shut-off" lies inside the stall gap. The 1D model puts it 15–35 % higher and predicts about twice the flow
   below it. It also ranks B and C above A, while the CFD puts A = B > C.
3. **Torque.** At 42.6k rpm, in mN·m:

   | suction | A | B | C |
   | --- | --- | --- | --- |
   | 400 / 600 / 750 Pa | 0.67 / 0.64 / 0.60 | 0.85 / 0.74 / 0.55 | 0.39 / 0.36 / 0.30 |
   | 850 Pa (flowing) | 0.44 | 0.44 | 0.28 at 775 Pa |
   | stalled (900–1000 Pa) | 0.10–0.11 | 0.11–0.13 | 0.17–0.18 |

   - **The 1D model's torque** at 750 Pa is 1.07 / 1.28 / 0.61 mN·m for A / B / C.
   - **Viscous share.** Pressure torque dominates; the viscous part is 0.03–0.08 mN·m.
   - **C** draws 45 % less torque than A on the flowing branch.
   - **B** draws 27 % more than A at 400 Pa, 15 % more at 600 Pa, 8 % less at 750 Pa and the same at 800–850 Pa.
     Its curved inlets shed periodically (±4 % torque oscillation in the steady solution). The likely reason: the air entering the eye already swirls with the rotor
     (the seal leak and the hub drive it), so the 24° inflow the curved inlets were drawn for isn't there.
4. **Operating points.** The CFD curves were run through the skirt (sealed, typical) and motor (400 kHz PWM, nominal)
   models (`tools/fan_study.py --cfd build/cfd/curves_medium.json`). Across the stall gap, flow and torque are
   interpolated between the last flowing and the first stalled point, i.e. as a time-mix of the two states (row "CFD").
   The row "CFD, no stall" instead extends the flowing branch smoothly past its last point: an optimistic bound if the
   real fan doesn't stall.

   | impeller | model | rpm at 4 N | shaft | battery | current | winding, 5 min | max force: 65k rpm cap / thermal only |
   | --- | --- | --- | --- | --- | --- | --- | --- |
   | A radial | CFD | 45.9k | 1.44 W | 2.46 W | 0.35 A | 59 °C | 8.0 N (cap) / 8.5 N at 67k |
   | A radial | CFD, no stall | 42.0k | 0.61 W | 1.46 W | 0.23 A | 55 °C | 9.4 N (cap) / 11.3 N at 71k (SF 4) |
   | A radial | 1D | 42.6k | 1.99 W | 3.03 W | 0.46 A | 60 °C | 7.7 N at 59k |
   | B curved inlets | CFD | 45.9k | 1.50 W | 2.53 W | 0.36 A | 60 °C | 8.0 N (cap) / 8.4 N at 67k |
   | B curved inlets | CFD, no stall | 42.7k | 0.91 W | 1.80 W | 0.28 A | 56 °C | 9.1 N (cap) / 10.3 N at 69k |
   | B curved inlets | 1D | 39.6k | 1.68 W | 2.61 W | 0.43 A | 57 °C | 8.6 N at 58k |
   | C backward | CFD | 48.4k | 1.35 W | 2.42 W | 0.33 A | 61 °C | 7.2 N (cap) / 8.4 N at 70k |
   | C backward | CFD, no stall | 45.2k | 1.02 W | 1.98 W | 0.29 A | 58 °C | 8.1 N (cap) / 9.6 N at 71k |
   | C backward | 1D | 41.1k | 1.65 W | 2.61 W | 0.41 A | 57 °C | 8.6 N at 61k |

   - **Seal recirculation at 4 N** (time-mix): 0.19–0.21 L/s. The 1D model has 0.34 L/s.
   - **The 65k cap.** The study's speed cap (65k rpm) now binds before the 85 °C limit for all three. The
     "thermal only" column lifts it, keeping the SF 4 structural limit (71k).

### Numerical checks and uncertainty

| check | result |
| --- | --- |
| mesh, A at 600 Pa (flowing), coarse / medium / fine | net 0.980 / 0.986 / 0.982 L/s, torque 0.641 / 0.642 / 0.655 mN·m, seal 0.091 / 0.085 / 0.087 L/s |
| mesh, A at 1000 Pa (stalled) | net −0.285 / −0.277 / −0.256 L/s (the backflow is the seal leak: 0.265 / 0.256 / 0.246), torque 0.098 / 0.100 / 0.098 |
| mesh near stall, A at 750 / 800 Pa, coarse vs medium | 0.862 / 0.745 (still falling) against 0.863 / 0.688 L/s |
| model: laminar instead of SST (coarse), A at 600 / 750 / 800 Pa | net 0.985 / 0.874 / 0.822 L/s against 0.980 / 0.862 / 0.745, torque 0.638 / 0.606 / 0.585 against 0.641 / 0.621 / 0.555 mN·m |
| fan laws: A at 55k rpm and 1250 Pa (= 750 Pa at 42.6k) | 1.141 L/s, 1.016 mN·m against 1.114 and 1.003 scaled: +2.4 % and +1.3 % |
| convergence | flowing stages away from stall settle to < 0.5 % std in flow and < 1.5 % in torque (B: 3 %, its inlet shedding), 1–3 % near stall (800–850 Pa); stalled stages 2–7 %; flow balance (inlet against ambient) within 0.6 %; initial residuals p 1e-5 to 3e-4, U 1e-3 to 2e-2, with the monitored integrals flat |

**What these mean:**
- **Discretisation.** About 2 % on torque and under 1 % on the flowing branch's flow. About 10 % on the stalled
  backflow, which is the seal leak and still falls with refinement.
- **Turbulence model.** The flow is transitional:
  - The gap Reynolds numbers are about 800–1000, and the disk's ωr²/ν is 4e4.
  - In the 0.3 mm gaps the SST eddy viscosity is only 0.3–2 times the molecular viscosity.
  - On the flowing branch away from stall, laminar and SST agree within 2.5 %, so the turbulence model is not what
    sets the numbers there.
  - Near stall the laminar run keeps more flow: at 800 Pa it still flows 0.82 L/s, against 0.69–0.75 with SST. So the
    stall point itself is uncertain by about ±50 Pa (mesh and model), which is about ±3 % in rpm.
- **The stall gap dominates.** Steady RANS can't tell what the fan does between its two branches. The time-mix and
  no-stall rows above bracket it:
  - for A at 4 N: 42–46k rpm, 0.6–1.4 W shaft, 55–59 °C;
  - for the maximum force: 8.0–9.4 N under the 65k cap.

  Real stall (rotating stall, surge of the small cavity) usually lands nearer the pessimistic end. Settling this
  needs an unsteady (sliding-mesh) run, or the bench.
- **Not in the uncertainty.** The geometry idealisations:
  - the 1.2 mm Ø40 cavity, where the real one is about 0.9 mm and the board's size;
  - a stationary motor shaft stub;
  - the motor model's own spread (R, L, friction; section 1), which moves the absolute temperatures more than the
    impeller choice does.

### Ranking

| | suction per rpm (stall point at 42.6k) | torque on the flowing branch | at 4 N | max force (65k cap) |
| --- | --- | --- | --- | --- |
| A straight radial | 850–900 Pa (best, with B) | reference | 45.9k rpm, 1.44 W, 59 °C | 8.0 N |
| B curved inlets | 850–900 Pa | −8 to +27 % against A | 45.9k rpm, 1.50 W, 60 °C | 8.0 N |
| C backward | 775–800 Pa (about 11 % lower) | 45 % less than A | 48.4k rpm, 1.35 W, 61 °C | 7.2 N |

- **Clear differences.** The stall points (A = B > C by about 90 Pa, against a ±50 Pa uncertainty), so C needs about
  5 % more rpm for the same force. The torque levels on the flowing branch also differ by more than the numerical
  error.
- **Not resolved.** Shaft and battery power at 4 N (within ±5 % of each other, against a stall-gap uncertainty of
  25–60 % that moves them all the same way) and the winding temperature (within 1.3 °C).
- **Ranking: A ≥ B > C.**
  - A makes as much suction as B for the same or less torque. It is the simplest to print and works in either
    direction.
  - The curved inlets (B) buy nothing in the CFD; the 1D model's 0.3 W gain doesn't appear.
  - C has the least torque but stalls earlier, so it runs faster for the same force and reaches less force under the
    speed cap.
- **What it means for the design.** The 1D model's recommendation (Ø22, 4 N at about 6 V) still holds, but expect
  about 46k rpm rather than 42.6k at 4 N, and recalibrate the voltage on the scale rig.
- **The stall gap is the main open question.** On the rig, look for:
  - suction that doesn't rise smoothly with voltage;
  - pressure ripple or noise from surge;
  - a jump in current between two duty settings.

  The CFD points to the inlet swirl from the seal leak as the trigger. Anti-swirl ribs in the board hole, or a
  tighter or labyrinth face seal, are candidates to delay it. They are untested; CFD or the bench would have to
  confirm them before any change to `micras/fan.py`.

Compute: about 23 h on 12 MPI ranks of the laptop's Core Ultra 7 155H, in docker capped at 14 GB and 16 CPUs (WSL).
The peak was 4.4 GB on the fine mesh. Speed was 1.1 / 2.2 / 4.2 s per iteration on the coarse / medium / fine mesh,
and the runs total 6.8 GB of case data.

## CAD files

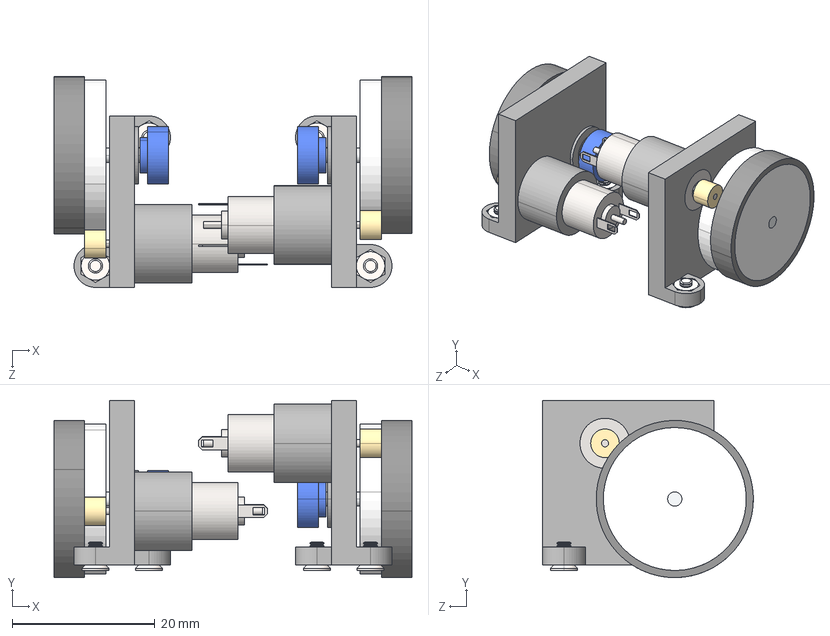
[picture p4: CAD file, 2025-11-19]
MicrasAssembly.STEP
50.1 x 24.8 x 29.5 mm
MancalEsquerdo
Maxon_DCX8M x 2
Pinhao x 2
CuboDeRoda x 2
Pneu x 2
Eixo x 2
Rolamento x 4
SeguraIma x 2
ImaEncoder x 2
hex nut style 1 gradeab_iso_ISO - 4032 - M2 - D - N x 4
hexa csunk flathd screw_iso_ISO 14581 M2x4x4-S x 4
MancalDireito

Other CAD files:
MicrasAssembly.SLDASM

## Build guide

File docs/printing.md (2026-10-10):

# Printing the Micras chassis

Everything goes through two commands: `tools/export.py` writes every part, turned to its print orientation, and
`tools/slice.py` lays out the plates and slices them into files the printers run (`.pm4n` for the Photon Mono 4,
`.gcode` for the Ender 3 V3 SE), with the profiles in `tools/slicing/`. The tools are open source and run on
Linux: PrusaSlicer slices both printers (supports for the resin parts), and UVtools converts the resin files to
the Mono 4's format. `tools/setup_print_tools.sh` installs them.

```sh
tools/capped.sh uv run tools/export.py              # build/print/<group>/*.stl
tools/capped.sh uv run tools/slice.py               # build/sliced/*.pm4n, *.gcode (and the plates as .3mf)
tools/capped.sh uv run tools/slice.py calibration --copy-to E:   # one plate, copied to the USB stick at E:
```

## 0. Exposure test (first, and whenever the resin changes)

The first parts came out with every hole too tight, much tighter than the flat calibration coupon predicted: the
exposure was too long for parts this thick. `tools/rerf.py` makes `R_E_R_F.pm4n` (about 45 min, 21 ml): with exactly
that file name, the Mono 4 runs Anycubic's exposure range finder and exposes 8 zones of the screen at 2.0, 2.25 …
3.75 s. Each zone gets one coupon (`fit_test.exposure_coupon`), printed on supports like the parts: a 14 × 38 × 3
block with holes at the exact sizes of the bought parts (motor Ø10, magnet Ø6, bearing Ø5, M2 nut, insert Ø3.2,
axle Ø2, motor shaft Ø1), a comb of 0.2–0.5 slots, and its number on top.

```sh
tools/capped.sh uv run tools/rerf.py --copy-to E:
```

Prepare, wash and cure it like the calibration print below. Then, for each coupon, try the real parts in its holes,
caliper its outside (14.00 × 38.00) and see which slots are open, and fill in the exposure table in
`docs/print_check.md`. The best exposure has the outside closest to size and its holes the least undersize while
the slots and edges are still sharp; the fits are then set at that exposure.

**Result (2026-10-03):** the outsides printed true at every exposure (37.94-38.02 x 13.93-14.04); the slots closed as
the exposure rose (all four open at 2.0 s, one at 3.75 s); at 2.0 s the bearing, motor, magnet, insert and motor shaft
each pressed into its nominal hole with some force (the axle hardest: its cut ends were rough). The parts now print
at 2.0 s and the fits in the code are set from that block.

**Second round (2026-10-03):** at 2.0 s the fits were good, but the parts were weak: some layers parted, the
impellers warped, the sensor caps and magnet cups felt fragile. The parts now print at 2.5 s, with every hole in the
code 0.05 bigger than the fits that worked at 2.0 s (at 3.0 s the holes had closed by about 0.1 more than at 2.0 s).

## 1. Calibration print (optional: to check the fits)

The fits are set from the exposure test above. The fit bars (`fit_test.fit_blocks`: one bar per fit, the bought
part tried in holes at several clearances, printed on supports like the parts; `build/sliced/calibration.pm4n`,
1.5 h, 38 ml, with the five sensor-cap variants) are there to check them if a fit turns out wrong. The older flat
coupon described below misled: printed flat with thin walls, its holes came out much looser than the parts'.

### The first, flat coupon (superseded)

## 1. Calibration print (once, before any part)

One resin print, `build/sliced/calibration.pm4n` (about 30 min, 7 ml), flat on the build plate with no supports. It holds every fit the robot uses at a
range of clearances, so the parts can be printed right the first time. The fits it measures belong to this resin
at this exposure (Anycubic ABS-Like Pro 2, 3.0 s): change either and it has to be printed again.

### Before printing

1. Room and resin at 25-30 °C (below 20 °C the resin needs about 30 % more exposure). Shake the bottle for
   a minute.
2. Vat: clean film, no cured flakes. After any failed print, run the printer's tank clean (it cures a layer over
   the whole film that you peel off with the debris) or sieve the resin: a cured flake under the plate can
   puncture the film. Fill to well above the minimum line.
3. Level the plate the way Anycubic describes for the Mono 4 (paper under the plate, home, tighten).
4. Copy `calibration.pm4n` to the USB stick and print it. Don't change any setting on the printer.

### After printing

1. Let it drip for 10 min, then slide the spatula under the coupon's bars from one end and lift it off the plate
   gently (it has no supports).
2. Wash in IPA: two baths of 2-3 min (no more than 6 min in all; long soaks swell the resin).
3. Let it dry completely: 30 min, no IPA smell left.
4. Cure briefly: about 2 min per side (or 3 min on the Wash & Cure's turntable). Over-curing makes it brittle
   and shrinks it.
5. Let it rest a day before measuring (or an hour at 50 °C): resin keeps shrinking a little after the cure.

### Reading it

Every tube and slot stands on a tab whose number is its clearance over the nominal size, in
hundredths of a mm (the size is the diameter, or across the flats for the nuts). The digits should read normally
(not mirrored). Measure 1 mm or more above the bottom, and push the test parts in from the top: the first layers
are over-cured on the plate and a little tight.

Try the real parts and note, for each row:

| Row | Test | Note |
| --- | --- | --- |
| PIN Ø2, Ø5, Ø8 | calipers on each pin, at half height, twice at 90° | the three diameters |
| BRG (bearing Ø5) | push a bearing in by hand | the smallest that takes it with a firm thumb press, and the smallest it just drops into |
| MOT (motor Ø9.61) | slide a motor in | the smallest it slides into with light friction, and the first that is loose |
| INS (insert Ø3.2) | drop an M2 insert in | the smallest it goes into without forcing (it will be glued) |
| AXL (axle Ø2) | push the 2 mm axle through | the smallest it slides through freely, and the smallest it pushes through at all |
| SHF (motor shaft Ø1) | push a motor's shaft (or a 1 mm pin) in | the smallest it presses into firmly, and the smallest it slides into |
| MG6, MG4 (magnets) | press each magnet in | the smallest it presses into with a finger |
| NUT (M2 nut) | press a nut in | the smallest it presses into and stays in |
| GAP (slots) | look through each slot at a light | the narrowest slot that is open all the way |

Also note anything that went wrong: a tube missing or torn off, warping, a soft or sticky surface (under-exposed),
lost detail or closed slots (over-exposed). Send the table back: the fits go into the parameters, and every part
is sliced again with them.

## 2. Set the fits

Results of the first coupon in ABS-Like Pro 2 at 3.0 s (2026-10-01): pins Ø2 / Ø5 / Ø8 measured 2.05 / 4.97 / 8.05
(the scale is right; outsides grow about 0.02-0.03 per side); the bearing presses in at +0.06 and drops in at +0.08;
the insert goes in at +0.10; the axle pushes through at +0.06 and slides at +0.10; the Ø4 magnet presses in at
+0.04; slots open from 0.30. So holes print about 0.06 small. The fits now in the parameters:

| Fit | Value | From |
| --- | --- | --- |
| bearing in a one-piece block (`solid_bearing_fit`) | +0.06 | measured: firm press |
| motor in a ring or the fan collar | +0.09 | like the bearing's drop-in |
| insert hole (`insert_d`) | 3.30 | measured |
| magnet cup, hub, race spacer on the axle (`axle_fit`) | +0.10 | measured: slides (glued) |
| printed pinion / wheel gear bores | 1.05 / 2.08 | press on the shaft / push on the axle |
| nut traps (`nut_af`) | 4.05 | hole -0.06 |
| magnet pockets | +0.04 | measured |

The rows not measured yet (MOT, SHF, NUT, MG6) are set from the same hole and outside offsets; check them on the
coupon when you can, and on the parts.

## 3. Resin parts (Photon Mono 4, Anycubic ABS-Like Pro 2)

Everything fits in one print, with the split drive blocks as an optional second (same preparation and
post-processing as the calibration print):

| File | What | Time, resin |
| --- | --- | --- |
| `robot.pm4n` | the whole robot's resin parts with the default drive (one-piece blocks): blocks, wheels (with their printed 36T), magnet cups (Ø4), fan mount, radial impeller. No pinions: the motors carry the brass ones (the brass 36T's wheels and drill guide are in `alternatives/`). The fan mount prints upside down | 2.1 h, 18 ml |
| `drive_split.pm4n` | the other drive variant (base + cap blocks) | 2.1 h, 11 ml |
| `trials.pm4n` | trial parts (`trials.py`): two impellers for the plain Ø1.5 shaft motor (`impeller_d155`, `_d158`: one and two dots), the tire cutting guide (base and ring), four wheel pairs with less backlash (`wheel_bl20/16/12/08`: 0.20 to 0.08 mm with the brass pinion, the value engraved on the gear's face) | 1.8 h, 27 ml |
| `skirt_guide_1.pm4n`, `skirt_guide_2.pm4n` | the skirt's placing jig and nose template, then its ring template (`skirt_guide_trim.pm4n`: the templates for acetate, optional) | 0.9 + 0.8 h, 43 ml |

```sh
tools/capped.sh uv run tools/slice.py resin drive_solid --merge robot
tools/capped.sh uv run tools/slice.py sensor_caps basket   # FDM
tools/capped.sh uv run tools/slice.py drive_split
tools/capped.sh uv run tools/slice.py trials
tools/capped.sh uv run tools/slice.py skirt_guide
```

The parts stand on braced supports (they come off as one piece: cut the tips with flush cutters, don't twist the
parts off) on a pad whose border is lifted off the plate, so the spatula slides under its edge.

### The two drive variants

The rest of the robot is the same for both. The motors sit straight in their rings (the backlash is what the
print gives).

| Variant | Blocks | Motors | Screws |
| --- | --- | --- | --- |
| `drive_solid` (default) | one piece per side; the bearings press in from either end against the ridge | each in a slit ring clamp | 2 ring clamps |
| `drive_split` | base + cap per side; the cap clamps the bearings and the left motor | the right one in a slit ring clamp | 4 cap screws + 1 ring clamp |

### Finishing the resin parts

Every part is turned so that its bores are vertical and its supports land on faces that don't matter; the few
working faces that must face down are flattened by hand (a minute each: fine sandpaper, 600-1000 grit, on glass,
figure-of-eight strokes):

- Cut the supports at their tips with flush cutters while the parts are soft, before the cure; the braced supports
  come away as one piece. Clip any nub flush with a blade.
- Bearing blocks: look into each bearing bore before fitting a bearing and scrape the lip's and the tube step's
  faces flat (a nub there stops the bearing seating); deburr the housing's inboard end (it runs 0.25 mm from the
  magnet cup).
- Motor rings: clear any nub off the ledge at the bore's outer end (the motor's front face sits on it).
- Magnet cups: clean the cone's tip (it bears on the inner race); deburr the flange face.
- Wheels: clean the cone on the end web's inner side (it bears on the outer bearing's inner race).
- Fan mount: it prints upside down, so the tabs' undersides (they seat on the blocks' ears and set the impeller's tilt and its 0.3 mm seal gap) come out clean; don't sand them. Clear the nubs off the tabs' tops so the screw heads seat.
- Inserts: their holes print sideways in the blocks; dry-fit an insert first, and run a 3.3 mm drill through if
  tight, then glue it with a drop of CA or epoxy (resin is a thermoset: heat-setting cracks it).
- Impeller: its bore is the 9T pinion's outline with 0.06 mm all round: it slides onto the pinion, the teeth key
  it; wick in thin CA. If it's tight, clean the bore by twisting the pinion in and out (don't drill it). Balance it
  afterwards (README, assembly).
- Pinions: two bores (the number on the file is the bore in hundredths): use the one that slides on the shaft with
  the least play, and glue it.

## 4. FDM parts (Ender 3 V3 SE)

| File | What | Notes |
| --- | --- | --- |
| `basket.gcode` | battery basket, PLA, upside down, the whole floor on supports from the bed (with a solid interface under it; round 7's left the bridged parts unsupported), 31 min, 4.8 g | the supports sit inside the box and come out through its open side |
| `sensor_caps.gcode` | the four wall-sensor caps and three test caps (1-3 dots: crush ribs 0 / 0.05 / 0.10), black PLA, front face down, no supports, solid (100 % infill), 0.08 mm layers (`pla_caps.ini`) | trim the brim flush with the hood's mouth; push a spare emitter and receiver into the test caps and keep the grip that holds them firmly without forcing (`FrontParams.rib_interf`) |

**Sensor caps (the resin ones, painted, did not work):** black PLA, and check the filament first. Some black
pigments let infrared through: print a 0.8 mm plate (the caps' wall), shine the emitter at the receiver through
it, and the reading should be the same as with the path blocked by a finger. If it isn't, try another black
filament (carbon-black pigmented).

Before the first print: run the printer's auto-levelling and set the Z offset on a first-layer test (the stock
start G-code loads the stored mesh with `M420 S1`). Clean the PEI sheet with IPA.

## How the settings were chosen

Resin (`tools/slicing/mono4.ini`, `resin_abs_pro2.ini`):

- **Orientation:** every critical bore and pin has its axis vertical (each layer then holds the whole circle at
  the 17 µm pixel resolution; tilted bores come out stepped, oval and skewed by the light that cures through to the
  layer below). Supports go on hidden faces; blind pockets open towards the plate or are vented (a cavity opening
  towards the film becomes a suction cup). The impeller is the exception: tilted 45° so its shroud's inner
  overhangs can be supported; its bore is shaped like the pinion, with a small clearance, and glued.
- **Supports:** 0.4 mm tips (0.3 is borderline on an FEP film), dense, 3 mm above a pad (the bottom layers'
  over-cure stays in the pad).
- **Exposure:** 2.5 s, from the exposure test and the parts printed at 2.0 s (section 0; Anycubic's table says 3.0 s, which closed every hole too far, and 2.0 s left the layers weak; the bottom layers at 45 s x 6, harder than its 35 s x 5, for the pad's grip), at
  25-30 °C. ABS-like resin is tough enough for the press fits, slit clamps and the 0.5 module gears; Standard is brittle.
  Anti-aliasing off (its grey edge pixels mostly don't cure and shift the edges; at 17 µm it gains nothing here).
- **Motion:** slow lifts (1 mm/s up, 2 mm/s down) so the soft fresh layers and the support tips bend less, and a
  2 s rest before each exposure so the resin film settles (even layers).

FDM (`ender3v3se.ini`, `pla.ini`): the V3 SE's machine values and start G-code from Creality's
OrcaSlicer profile; Arachne perimeters; PLA at 210 °C with full cooling and 25 mm/s bridges.

Sources: [cross-layer curing and layer bulging](https://blog.honzamrazek.cz/2022/11/cross-layer-curing-and-layer-bulging-on-resin-printers-enemy-of-overall-dimensional-accuracy-and-printed-threads/),
[resin shrinkage and exposure bleeding](https://blog.honzamrazek.cz/2022/06/getting-perfectly-crisp-and-dimensionally-accurate-3d-prints-on-a-resin-printer-fighting-resin-shrinkage-and-exposure-bleeding/),
[Formlabs: model orientation](https://formlabs.com/eu/support/Model-Orientation/),
[Formlabs: suction cups](https://formlabs.com/support/Preventing-suction-cups-in-PreForm/),
[AmeraLabs: support experiment](https://ameralabs.com/blog/experiment-3d-printing-supports/),
[Liqcreate: anti-aliasing and blur](https://www.liqcreate.com/supportarticles/explained-tested-anti-aliasing-aa-and-blur-in-resin-3d-printing/),
[UVtools: rest times](https://github.com/sn4k3/UVtools/wiki/Rest-times-and-TSMC),
[Anycubic: resin settings](https://store.anycubic.com/blogs/news/resin-settings-for-anycubic-3d-printers),
[PrusaSlicer CLI](https://help.prusa3d.com/article/command-line-interface_1694),
[UVtools](https://github.com/sn4k3/UVtools).

## If something goes wrong

| Symptom | Likely cause | Fix |
| --- | --- | --- |
| part missing, pad on the film | supports tore off (peel force) | check the plate level and the film; more support density |
| layers split, soft or sticky surface | under-exposed or cold resin | warm the room/resin to 25 °C; then +0.3 s exposure (reprint the coupon) |
| slots closed, holes small, details bloated | over-exposed | -0.3 s exposure (reprint the coupon) |
| printer won't list the file | the converted .pm4n | open the plate's `.3mf` in Lychee and slice it there with the settings above |
| Ender stops mid-print and beeps (thermal-runaway protection) | the nozzle cooled below its target: the part fan's air on the heater block, or a loose thermistor or heater cartridge | check the heater block's silicone sock and that the thermistor and heater cartridge are tight; test: heat the nozzle to 215, fan at 100 % from the screen, watch the temperature for 3 min (it should stay within 2-3 °C); `pla_caps.ini` runs the fan at 50-70 % |
| basket floor sags or strings | bridges | check cooling (100 %) and that the supports printed; lower `bridge_speed` in `pla.ini` |

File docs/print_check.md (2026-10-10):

# Print check sheet

Fill in the **Result** column: `ok`, `tight`, `loose`, `broken`, or a short note. Measurements in mm. Write `L: … R: …`
when the sides differ. Leave a row empty if you didn't check it.

## Prints

| Print | Failed / missing parts, other problems |
| --- | --- |
| print1_robot (resin) | |
| print2_drive_variants (resin) | |
| skids (resin) | not used: mouse skates instead |
| basket (PLA) | floor bridges failed without supports (rest fine); needs ~3 mm more length |

## Exposure test (R_E_R_F)

For each coupon (its number is on top): does the real part go in its hole? Write `in` (slides), `press`, or `no`.
Then the outside with calipers, and the narrowest slot that's open.

| # | Motor Ø10 | Magnet Ø6 | Bearing Ø5 | Nut | Insert Ø3.2 | Axle Ø2 | Shaft Ø1 | Outside (14 × 38) | Slots open from | Notes |
| --- | --- | --- | --- | --- | --- | --- | --- | --- | --- | --- |
| 1 | press | press | press | | press | press (much force) | press | 37.98x13.95 | 4 | |
| 2 | | | | | | | | 37.94x13.93 | 3 | |
| 3 | | | | | | | | 37.95x13.94 | 3 | |
| 4 | | | | | | | | 37.98x14.04 | 3 | |
| 5 | | | | | | | | 38.02x14.00 | 3 | |
| 6 | | | | | | | | 37.97x13.98 | 2 | |
| 7 | | | | in | | | | 38.00x13.99 | 3 | |
| 8 | | | | press | | | | 38.00x13.98 | 1 | |

## Calibration coupon: the rows not measured yet

| Row | Which cell | Result |
| --- | --- | --- |
| MOT | the motor slides in with no play | this part did not fit to the plate |
| SHF | the motor shaft presses in | no one |
| NUT | an M2 nut presses in and stays | 0 |
| MG6 | the Ø6 magnet presses in and stays | 4 |

## Drive (variant used: ______________)

| Part | Check | Design | Result |
| --- | --- | --- | --- |
| Blocks | printed complete, faces clean | | |
| Blocks | bearings: held, no play | Ø5.10 split, Ø5.06 one-piece | don't go in, even with a lot of force |
| Blocks | sleeve turns in its seat (or motor slides in, no-sleeve) | Ø12.05 / Ø9.70 | |
| Blocks | inserts go in; nuts stay in their traps | Ø3.30 / 4.05 AF | inserts ok; nuts need too much force |
| Sleeves | motor slides in to the lip, no play | Ø9.70 | |
| Sleeves | turning them sets the gear mesh | | |
| Magnet cups | magnet fits; slides on the axle | Ø6.04 / Ø2.10 | magnet fits well; the boss around the axle is too thin, broke |
| Race spacers | thickness | 0.55 | too small to handle, didn't survive |
| Wheel hubs | tire sits straight in the channel; wheel runs true | tire Ø22.08 mounted | |
| Gears | teeth complete; bores fit (pinion press, wheel push-on) | Ø1.05 / Ø2.08 | shaft into pinion: extreme force; axle into wheel gear: too much force |
| Gears | mesh: turns freely, no play, no tight spots | | |

## Fan

| Part | Check | Design | Result |
| --- | --- | --- | --- |
| Impeller | blades and shroud complete; bore reamed | Ø0.97–0.98 | |
| Impeller | vibration at full speed (none / some / bad) | | |
| Fan mount | motor slides into the collar; clamp holds | Ø9.70 | |
| Fan mount | tabs sit in the ear recesses, foot on the MCU | | |
| Fan mount | impeller spins without touching | 0.3 gap at the board | |

## Sensor caps

| Part | Check | Result |
| --- | --- | --- |
| W1–W4 | printed complete | |
| W1–W4 | slide on; the fork takes the legs, the tab goes in the keyway | too tight to fit |
| W1–W4 | grip on the LEDs (none / light / firm / too tight) | |
| W1–W4 | base flat on the board, LEDs look straight | |
| W1–W4 | paint blocks IR (phone camera shows no glow through it) | |
| Test caps | best grip (1–3 dots) and best signal (3, 4 or 5 dots) | |

## Skid pads

| Notches | 1 | 2 | 3 | 4 | 5 |
| --- | --- | --- | --- | --- | --- |
| Design thickness | 0.85 | 0.80 | 0.75 | 0.70 | 0.65 |
| Measured | | | | | |

Pair glued: ___ notches. Paper check result: ______________

## Battery basket

| Check | Result |
| --- | --- |
| floor bridges clean, not warped | |
| cells fit (not tight, no rattle) | |
| pegs, feet and screws fit on the caps | |
| strap goes through the lugs | |

## Assembled robot

| Check | Design | Result |
| --- | --- | --- |
| mass with battery | 84 g | |
| board height above the floor, fan off / fan on | 1.2 / ~0.75 | |
| anything rubbing or touching | | |

## Other problems

- Drive motor is Ø10.0 (as its datasheet says), not 9.61.
- Fan motor is Ø9.97 and has a 9T M0.3 pinion on its shaft, 4.6 long.
- Most holes print much smaller than the coupon predicted: exposure (and the coupon method) to be redone.
- Exposure test done: parts now print at 2.0 s, fits set from block 1 (no new calibration print). The axle's cut ends were rough: deburr them.
- Second round at 2.0 s: fits mostly good, but weak layers and warped impellers. Now 2.5 s with every hole +0.05; magnet
  pocket a little tighter; bearings measure 2.57 wide (pockets were 2.5: now 2.67); impeller bore shaped like the
  pinion; sensor caps and magnet cups thicker; the opening under the receiver is straight-sided now.
- Third round (2.5 s): much better. Changes: fan mount without the front leg; split bearing pockets 5.20 (5.13 stopped
  the cap) and a bearing fit bar (fit_BRG, 5.10-5.30) in the robot print; basket peg sockets 2.4; motor in sleeve back
  to 0.10; axle bores 2.08 (loose at 2.15); magnet pocket 6.02; two pinion bores (1.07, 1.03); sensor caps with both
  legs on the board and a loose flat for the emitter's flange; new axle stack: one-piece wheel (gear, drum, end web)
  turning round a tube that carries the outer bearing inside the wheel, bearings 5.9 mm apart, magnet cup with a
  3.4 mm sleeve; no test caps (which dots were best?).
- Test caps: 2 dots (ribs 0.10) gripped best and the 2 deg pitch was good: the caps now use both.
- Bearing fit bar (2.5 s): the bearing slid into the 5.10 hole with no force. Tube and one-piece seats now 5.05.
- Round 3 blocks: split pocket 5.20 (cap closes, no rattle): kept. Tube 5.15: bearing loose, now 5.05.
- Magnet cup on the axle a little loose at 2.08: now 2.04 (the wheel stays 2.08).
- Round 4 feedback: fan clamp nut turned with the screw (its trap broke out of the 4 mm ears): ears now 6 mm, nut
  flats up and down. Right ring clamp had no way to fit its insert (the pocket opened only into the slit): it now goes
  in from under the lower ear. Motor fits: sleeve 0.06 (was 0.10), split no-sleeve 0.06, one-piece no-sleeve 0.15.
  Default drive: split blocks without sleeves.
- Ring clamps: an M2 nut trapped under the lower ear instead of the insert. Fan motor collar 0.10 (0.15 was loose).
- Wheel grip on the axle 1.4 mm (could tilt): outer bearing moved 1.5 mm in, the wheel's boss now grips 2.9 mm; bearings 4.4 mm apart.
- Alternative magnet cups for the Ø4x2 magnet (magnet_cup4_L/R), its face 0.5 mm from the chip like the Ø6 (the field estimate there is over the chip's 70 mT window: check the encoder's readings).
- Board screws into the bases: M2 nuts in side slots (a boss round each hole above the 1.8 mm lift, nut 1.9-3.5 mm above the board) instead of glued inserts.
- Emitters wrapped in electrical tape: the emitter's body bore and ribs 0.2 mm bigger all round (one wrap of ~0.18 mm tape; not over the flange).
- Board-screw nuts lowered to 0.9 mm above the board (like the v1 blocks); still in side slots (a well from above would cut the bearing housing over the front holes).
- Wheel bore on the axle 2.04 (2.08 a little loose). Ø4 magnet cup: 0.75 mm wall round the magnet (head Ø5.5), was the Ø6 cup's outside.
- Cap-screw insert pockets in the split bases 2.3 deep (2.0 was too shallow).
- Upper (right) motor ring, split no-sleeve: 0.10 (0.06 a little tight); the left motor stays 0.06.
- Upper (right) motor ring: 0.15 (0.10 from round 4 should be bigger; the 0.06 in between was my mistake, applying the left seat's fit to both).
- Round 5 feedback: the motor rings were thicker than needed (drawn for the sleeves) and the motors needed more support. Eccentric sleeves dropped (two drive variants: `drive_split`, `drive_solid`); motor rings 1.5 mm wall, centred on the motor, running inboard to 1 mm short of the centre line (14 mm of grip, was 7.4) with a slot round each encoder board; the motor's front face stops on a 1 mm flat ledge before the cone (it rested on the cone's rim). Battery tray 1 mm lower (28.0). The Ø4x2 magnet is now the default cup (`magnet_cup`); the Ø6x2 cup (`magnet_cup6`) is the alternative.
- The Ø6 cup clipped the caps (0.14 / 0.27 mm³ at the room's outer end): the frame boss's blend into the sleeve-sized ring was added after the cup's room was cut. The room (and the encoder slot) is now re-cut after the blends, and check_layout checks the cups (the Ø6 one too) and the wheels against the blocks: it allowed any contact between them as a running gap. The right frame boss is blended into its ring from the ring's inboard end (it stood clear of the thin ring and would have started in mid-air).
- Clamp screws closer to their motors, 0.6 mm of resin between the nut trap and the bore: the upper drive motor's 1.1 mm (7.65 from its axis; the trap runs on down through the ring's outside), the fan motor's 0.5 mm (7.94; the ears end the same 2.6 past the screw). The upper ring's clamp moved inboard to y 8.9 (the middle of the longer ring): further out, the housing's blend into the ring lay under its nut trap and blocked the nut going in from below.
- Round 6 viewer feedback: the cap screws' countersinks left a 0.25 mm skin on the caps' outer face over the heads (in r5 too: it prints as a ceiling and broke into points and fins): the head's clearance now opens out through the face. The right cap's front screw column was raised to a near-tangent join with the thin ring and the clamp's slit cut a flake off it: a column joins the ring only where they overlap by more than the ring's wall. Left cap: the rear basket peg moved onto the frame boss's flat top (its socket at x -15 ran into the rear screw's countersink), and the front socket has a flat landing across the plate (it opened lopsided on the slope), with no lightening pocket under it. One-piece left clamp: the ear runs a wall past its nut both ways (0.1 mm before).
- Seen from behind: a wedge of the boss's blend into the ring refilled the rear cap screw's countersink (the heads are now cut again after the blends); the head clearance clipped a lens off each motor ring (the rear cap screws moved back, to x -19.2 left and -13.0 right, so the clearance stays 0.3 off the ring); the right frame boss showed its bottom 0.3 below its blend and later a 0.05 strip down its back (it now stands from the blend's floor, inside the blend and the web, which are drawn 0.05 wider) and moved in to y 10.28, 0.6 clear of the rear screw's head.
- Round 6 built: the left wheel turned heavy on every tooth (not freed by loosening the cap), the right one free but with almost no backlash; the left pair had none. The geometry is the same both sides (every running gap measured equal), so the print closed both meshes by about 0.06-0.09 mm against the 0.06 mm designed. Backlash now 0.12 mm in the pair (0.10 on the pinion, 0.14 on the wheel, whose teeth have the wider tips): the teeth bind only after the centre distance closes by about 0.15-0.19 mm. For the round-6 robot: pinions with all the extra on them (`gear_r6_bl12_*`, `gear_r6_bl14_*`, both bores), in the robot print.
- Round 6: the sensor caps did not work in resin (painted). They are now black PLA on the Ender, front face down with the bores vertical, no supports, solid (100 % infill), 0.08 mm layers (`tools/slicing/pla_caps.ini`): bores 0.25 mm radial clearance (0.175), crush ribs 0.6 wide (0.5) and 0.05 interference until the three FDM test caps (0 / 0.05 / 0.10) choose, keyway cover 0.8 (0.6) and tab clearance 0.15 (0.125). Check the filament blocks IR first (docs/printing.md).
- The brass gears arrived: the motors carry the brass 7T pinions (no printed pinions, nor the round-6 retrofit ones), and the default wheel is for the bought 36T (`Gears.wheel_gear = "brass"`): no printed teeth; the gear is drilled in the printed guide (`gear_guide.py`: bore to Ø7.8, three Ø2.2 holes on Ø12.3, countersunk by hand) and screwed on with three M2×5 flat heads (the guide is square outside for a vise, its pocket has the gear's tooth outline so the gear can't turn, and the square lid can't turn in its recess), flush on its inboard face, into nuts in hex pockets in the wheel's outer face. The drum stays hollow: each pocket is in a column from the end web to the gear, and the gear touches only the three column ends (the owner's request; 0.66 cm³ a wheel, was 0.96 with the drum filled). The printed-gear wheels are in `alternatives` (they run with the brass pinion at about 0.25 mm of backlash). One-piece blocks are now the default (`drive_solid` in the robot print; `drive_split.pm4n` is the option). check_layout: 0 issues for both variants (the flush heads keep the gear's 0.25 mm running gap to the block). Sensor caps print one at a time (`complete_objects`, 46 mm apart for the head).
- Round 7 built and worked well. Of the two wheel gears tried with the brass pinions, the printed 36T was preferred over the drilled brass one: `Gears.wheel_gear = "printed"` is the default again (the brass 36T's wheels and drill guide move to `alternatives/`). The fan mount sits tilted a little upward (front up) instead of hanging level, because of how its tabs seat on the blocks' ears; a new way of holding it is being worked out.
- Round 7: the fan mount now prints upside down (collar down). Collar up, the tabs' undersides that seat on the blocks' ears were on supports, and their nubs tilted the fan's front up by more than 1 mm. Upside down they print as clean top faces; the slice shows no supports inside the motor bore (the seat prints as an unsupported 1.6 mm ledge). The basket's floor sagged in its thin parts: PrusaSlicer left out supports under what it took for bridges (almost all of the 0.4 mm skin, only patches round the posts were supported); `pla.ini` now has `dont_support_bridges = 0`, 1.5 mm support spacing and 3 interface layers, so the whole floor sits on supports.
- Round 7: the sensor caps' print (Ender) stopped mid-way with an alarm, the thermal-runaway protection (the nozzle fell below its target). `pla_caps.ini` now runs the part fan at 50-70 %, ramped over the first 4 layers (pla.ini's 100 % from layer 2), and one nozzle temperature, 215.
- Trial plate (`trials.py`, `trials.pm4n`), the default design untouched: impellers for a fan motor with a plain Ø1.5 shaft, 6 mm out (it fits the same mount; the shaft isn't cut: the bore's bottom stops it where the pinion put the hub), bores 1.55 and 1.58 (they print about 0.06 small: a hard press and a snug push; ream with a Ø1.5 drill by hand if too tight); a tire cutting guide (cut at the channel's 3.2 mm); wheel pairs with 0.20, 0.16, 0.12 and 0.08 mm of design backlash with the brass pinion (printed 36T unshifted, 0.85 / 1.40 addendum / dedendum for 0.2 mm of tip clearance each way: `check_gears.py` shows them free until the centre distance closes by 0.15-0.20). To report: which pair runs smoothest without binding, which impeller bore holds, how the tires cut.

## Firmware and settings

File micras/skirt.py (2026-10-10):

"""Suction skirt: a plastic film taped under the board, and a nose doubler of the same film.

The film is chosen by the downforce measured on the scale rig: 10 um polyethylene bag film, 40 um cellulose acetate
or a thicker polyurethane (TPU) film, all cut from this one pattern. The inner band (tape_w) is taped to the
underside along the board edge; the lip (margin) sticks out past the edge and trails outward along the floor, so the
suction under the board presses it down. It must touch the floor: a 0.1-0.3 mm gap under it costs 12-53 % of the
downforce (docs/fan_study.md). The board's edge rides 0.9-1.5 mm up (tire sink, rocking onto the skates, 0.5 mm
steps at the maze's board joints), so the 2 mm lip reaches the floor with 0.5 mm to spare. Soft films seal best and
are too limp to hold the board up; the price is that they fold under at board joints, so a second layer of the same
film (the doubler) is laminated under the skirt along the nose. A stiff film (acetate) carries part of the robot's
weight on its lip, which takes it off the tires: trim its lip at the trim line, where it just reaches the floor.

The lip runs all the way round, the wheel notches included (an open notch leaks about 50 mm^2 and caps the fan at
about 3.5 N, docs/fan_study.md). In the notch the lip reaches |y| 19.25 at the bottom face and x +-6.5 at the end
faces, under the board's underside: the tires (inner face |y| 21.3, 2 mm up at x +-6.5) stay 0.7 mm clear and the
wheel gears 1.5 mm. The skates are stuck to the board just inside the taped band (0.2 mm in from its inner edge).

Polyethylene is a low-surface-energy plastic that ordinary tape doesn't hold: tape its band with an LSE adhesive
transfer tape (3M 9472LE) or clamp it under a Kapton tape strip laid over it.

skirt_sheet.py draws both pieces at 1:1 with rulers and an ID-1 card outline, to trace the film from a screen.
"""

from dataclasses import dataclass

from build123d import Align, Box, Pos, make_face, offset

from .layout import board_simple
from .params import P, Params


@dataclass(frozen=True)
class SkirtParams:
    margin: float = 2.0  # the lip, past the board edge: reaches the floor from 0.9-1.5 mm up
    tape_w: float = 3.0  # the taped band, inside the board edge; the skates sit just inside it
    trim: float = 1.5  # trim line past the board edge, for stiff films: the lip just reaches the floor
    doubler_x: float = 32.3  # the nose doubler covers the skirt ahead of this x: the nose, its chamfers and corners


SK = SkirtParams()


def board_outline(p: Params = P):
    """The board's outer outline (notches included, holes left out) as a face at z = 0."""
    pcb, _ = board_simple(p)
    bottom = pcb.faces().sort_by().first
    face = make_face(bottom.outer_wire())
    return Pos(0, 0, -face.bounding_box().min.Z) * face


def pattern(p: Params = P, sk: SkirtParams = SK):
    """Flat skirt shape (a face in the XY plane, robot frame, seen from above), to cut 1:1."""
    board = board_outline(p)
    return offset(board, sk.margin) - offset(board, -sk.tape_w)


def doubler(p: Params = P, sk: SkirtParams = SK):
    """The nose doubler: the skirt's band and lip ahead of doubler_x, laminated under the skirt there."""
    skirt = pattern(p, sk)
    bb = skirt.bounding_box()
    length = bb.max.X - sk.doubler_x + 1
    keep = Pos(sk.doubler_x, 0, 0) * Box(length, bb.size.Y + 2, 2, align=(Align.MIN, Align.CENTER, Align.CENTER))
    return skirt & keep


def export(out_dir, p: Params = P, sk: SkirtParams = SK):
    """build/skirt.dxf|svg (the skirt alone) and the cutting sheet, build/skirt_sheet.svg|pdf|png."""
    from build123d import ExportDXF, ExportSVG, Unit

    from . import skirt_sheet

    face = pattern(p, sk)
    for exporter, name in ((ExportDXF(unit=Unit.MM), "skirt.dxf"), (ExportSVG(unit=Unit.MM), "skirt.svg")):
        exporter.add_shape(face)
        exporter.write(str(out_dir / name))
    skirt_sheet.export(out_dir, p, sk)
    return face


if __name__ == "__main__":
    from pathlib import Path

    out = Path(__file__).resolve().parents[1] / "build"
    out.mkdir(exist_ok=True)
    export(out)

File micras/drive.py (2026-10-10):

"""Printed drivetrain parts: bearing block base + cap per side, magnet cups, wheels.

Each side's block is split at the axle plane (z = axle_z). The base is screwed to the board through
the two countersunk holes; the cap clamps the inner bearing (and, on the left, the level motor)
with two screws into inserts in the base. The right cap also carries the clamp ring of the raised motor. A tube
on the base (one piece with it, not split) reaches out from the block through the wheel's gear into its hollow drum
and holds the outer bearing at its end, pressed in from the end up to a step (Params.AxialStack).

Layout.blocks = "solid" (the default) makes each block one piece instead: the inner bearing presses in from the inboard end
(through the magnet cup's room) up to the lip, and both motor rings are slit clamps (the left one on its rear side).
The motors sit straight in their rings (the eccentric sleeves are gone: the thin rings let the battery sit lower).
"""

from dataclasses import dataclass
from math import atan2, cos, degrees, radians, sin, tan

from build123d import (Align, Box, Circle, Cone, Cylinder, Line, Plane, Pos, Rectangle, RegularPolygon, Rot,
                       ThreePointArc, Wire, extrude, make_face, make_hull, mirror, offset)

from .layout import board_boxes
from .params import P, Params

MIN = (Align.CENTER, Align.CENTER, Align.MIN)
MAX = (Align.CENTER, Align.CENTER, Align.MAX)


@dataclass(frozen=True)
class DriveParams:
    wall: float = 1.2  # around the bearing bores
    motor_wall: float = 1.5  # the motor rings (2.1-2.7 when they were drawn for the sleeves)
    bearing_fit: float = 0.20  # diametral clearance on the bearing OD in the split pocket: it drops into the base;
    # the split closes by split_relief, which leaves a light clamp (at 2.5 s: the cap closes, no rattle; 0.13 stopped
    # the cap)
    # fits for ABS-Like Pro 2 at 2.5 s (docs/printing.md): outsides print true; the holes printed about as at 2.0 s
    # (the motor and the magnet came out loose with 0.05 added), except the bearing pockets in the blocks
    pillar_wall: float = 1.0  # around the glued cap-screw inserts
    plate_t: float = 2.4  # outer plate skin where it is pocketed from the inboard side
    pocket_rim: float = 1.0  # solid rim around the pockets, along the plate's outline
    pocket_margin: float = 0.8  # pockets stay this far from the rings, screw columns and housing web
    split_relief: float = 0.05  # taken off the cap's split face: tightening the cap clamps bearings and motor
    # (0.15 with the holes printing small crushed the bearings: the split blocks fitted worst)
    # the motor's fits (diametral; the clamp or the cap holds it), from the parts printed at 2.5 s:
    ring_motor_fit_split: float = 0.06  # no sleeves, split blocks: the level (left) motor, clamped by the cap (0.10
    # was a little loose)
    ring_motor_fit_split_upper: float = 0.15  # no sleeves, split blocks: the raised (right) motor in its slit ring
    # (0.10, printed in round 4, should be bigger; the slit clamp closes the rest)
    ring_motor_fit_solid: float = 0.15  # no sleeves, one-piece blocks (0.10 needed too much force: the ring has no
    # cap to open)
    seat_front: float = 0.6  # the ring runs on this far past the motor's front face
    stop_ledge: float = 1.0  # radial: the flat ring the motor's front face sits on, then the 50 deg cone (a wider flat
    # end would be a ceiling inside the bore as it prints, and sag)
    seat_min_y: float = 1.0  # the rings run inboard past the encoder daughterboards (slotted round them) to just short
    # of the centre line (the two rings would meet past it); 7.6, outboard of the encoder boards, gripped 7.4 mm
    clamp_min_y: float = 7.6  # the one-piece left clamp's ear starts here at most (further in if its nut needs it)
    pad_inset: float = 0.3  # stay inside the silkscreen contact outline
    lift: float = 1.8  # everything except the pads starts this far above the board top
    pad_h: float = 3.0  # contact plate thickness
    insert_d: float = 3.35  # threaded insert hole in resin (M2x2 OD 3.2, glued in): goes in without forcing
    insert_l: float = 2.0
    cap_insert_depth: float = 2.3  # the cap screws' insert pockets in the split bases: deeper than the insert, so it
    # seats fully below the split face with room for the glue (2.0 was too shallow)
    screw_clear_d: float = 2.2
    screw_l: float = 5.0
    csk_d: float = 4.0  # countersink for the M2 flat heads in the caps
    cap_screw_y: float = 16.0  # |y| of the cap screws, at most (the head stays 0.3 clear of the gear cut-out)
    cap_screw_front_x: float = 5.2  # clear of the fan mount feet; the rear screw's x is found per side (cap_screws)
    frame_screw_depth: float = 3.8  # M2x5 through a 1.2 frame floor
    frame_boss_top_left: float = 22.0  # keeps the screw tip 0.5 above the left seat bore
    tray_bottom_z: float = 28.0  # frame tray underside, sits on the right boss (0.22 over the raised motor's ring;
    # 29.0 with the rings drawn for the sleeves)
    slit: float = 0.8  # clamp slit in the motor rings (the raised one; both in the one-piece blocks)
    ear: float = 2.2  # clamp ear thickness either side of the slit (M2x5 then engages 2 mm)
    clamp_nut_wall: float = 0.6  # resin between a ring clamp's nut trap and the motor bore: the screw as close to the
    # motor as that allows (its nut was all outside the ring: the ears reached 1.1 mm further out)
    # ear on each cap for the fan mount's arm: in front of the front cap screw (clear of its head), top level
    # with the left cap's front column; an M2 screw comes down through the arm's tab into a nut trapped under it
    fan_ear: tuple = (10.2, 14.2)  # (x, |y|) of the screw
    fan_ear_r: float = 3.3
    fan_ear_t: float = 2.9
    fan_tab_r: float = 2.5  # the arm's tab drops into a recess in the ear's top: it locates the fan mount
    fan_recess: float = 0.5
    nut_af: float = 4.15  # M2 nut across flats, with fit (4.10 at 2.0 s; 4.05 needed too much force; glue if loose)
    nut_t: float = 1.6
    # the board screws' nuts (from under the board, an M2x5 reaches about 4 mm above the board top), like the v1
    # blocks: 0.9 mm of resin under the nut (the owner's choice). Below the lift the pad must stay inside the
    # silkscreen tab (2.7 mm radius round the hole), so the nut's lower 0.9 mm has thin walls at its corners (~0.3);
    # above the lift a boss holds it. It slides in from the side: a drop-in well from above, as in v1, would cut the
    # bearing housing over the front holes
    board_nut_z: float = 0.9  # nut bottom above the board top
    board_nut_wall: float = 1.0  # round the nut's corners, in the boss
    board_nut_roof: float = 0.6
    # the battery basket's feet (frame.py): (side, x) on each cap's outer plate, on its mid-plane; a peg on the
    # foot drops into a socket in the cap (it places the basket before its screws go in), "pad" feet only rest
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

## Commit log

2025-11-14 add 3d files
    [Base.SLDPRT, Base.STEP, CuboDeRoda.SLDPRT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]
2025-11-19 update cad files
    [Base.SLDPRT, EncoderBoard.SLDPRT, EncoderBoard.STEP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]
2025-12-01 update solidwork files
    [Base.SLDPRT, Battery.SLDPRT, CuboDeRoda.SLDPRT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]
2026-09-26 update latest cad files
    [Base.SLDPRT, Battery.SLDPRT, CuboDeRoda.SLDPRT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]
2026-09-26 update SolidWorks part files
    [SeguraVentoinha.SLDPRT, Ventoinha.SLDPRT]
2026-09-26 add Velcro part file to the repository
    [Velcro.SLDPRT]
2026-09-26 add new part files for EngrenagemRoda, PinhaoEngrenagem, and PinhaoVentoinha
    [EngrenagemRoda.SLDPRT, PinhaoEngrenagem.SLDPRT, PinhãoVentoinha.SLDPRT]
2026-09-30 add parametric build123d chassis skeleton
    Board reference import (kicad-cli STEP/STL + mechanical JSON), bought-part
    models and layout in the firmware robot frame, split bearing blocks with
    eccentric motor sleeves, magnet cups, race spacers and wheel hubs.
    Includes clash and board-contact-zone checks, a mass model with a battery
    arrangement study, and render/viewer tools.
2026-09-30 add fan, top frame and cap frame bosses
    Closed radial impeller with a face seal over the clean silkscreen ring and a
    three-foot mount on free board spots, a PETG top frame with the battery tray,
    cap posts and a fan tube, real motor/brass gear masses, a standing-cells
    option in the battery study, and fan/frame parts in the checks.
2026-09-30 add sensor caps and nose bumper with floor skid
    Four slide-on resin caps align and shield each emitter/detector pair; a
    replaceable PETG nose screws to a boss on the frame's fan tube, bears on the
    board's front edge and carries the skid. The zone check now uses the real
    PCB outline, and tools/check_sensors.py checks the caps against the LED bodies.
    [assembly.py, frame.py, front.py]
2026-09-30 add straps, skirt pattern, exports, mass report and design tests
    TPU battery straps, a 1:1 skirt cutting pattern (DXF/SVG), STL/STEP export
    with a material and print-notes table, a mass report built from the real
    parts, stacked battery centred for CoM over the axle, and pytest wrappers
    around the design checks.
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2026-09-30 show.py: explain how to open the viewer instead of failing with tracebacks
2026-09-30 race-car body, walled battery box, symmetric fan mount, full screw engagement
    - battery: cells on edge one behind the other (layout study: same inertia as the
    pyramid, 2 mm lower), full-height box walls and a screwed lid replace the straps
    - body.py: F1-style halo with a central pillar, front wing with nose cone and
    skid bearing on the board edge, engine-cover lid with gills, shark fin and
    rear wing
    - fan mount: symmetric (two feet + two ears screwed to the frame's airbox tube);
    the tube's lugs capture the fan motor axially
    - countersunk helper: every M2x5 now reaches the full 2 mm insert (fixes cap
    screw heads being countersunk in the wrong place)
    [assembly.py, drive.py, fan.py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]
2026-09-30 fix front wing and lid screw engagement; document all fasteners
    [frame.py]
2026-09-30 one-piece car body: fold nose, front wing and fairing into the frame; drop the halo
    The top is now two PETG parts: the body (frame, battery box, engine-cover
    fairing, hollow nose cone, front wing with skid) and the lid (gills, fin,
    rear wing). 15 screws instead of 18; yaw inertia 36.0k (was 37.2k).
2026-09-30 printable body (upside down, no supports), slim ridged nose, separate flat-printed front wing, soft edges, overhang checker
2026-09-30 faceted wedge body printed on its nose plane
    The nose is one flat plane from the lid down to the tip (inspired by the
    reference photo), with side facets, LED windows and the fan motor poking
    through. The body prints lying on that plane; the box floor is ribs (no
    ceiling), the spine plate is gone, the lid slides under the plane with two
    rear screws, and a lug under the plane holds the fan motor. overhang.py
    gains --down and reports regions in the robot frame; normals now come from
    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
2026-09-30 front wing merged into the body, nose flush with the lid, four-screw lid
    The short wing (2.5 mm ahead of the board edge) has its top rising towards
    the front, so the body still prints lying on the nose plane. The nose plane
    now starts flush with the lid's top; the lid is held by four corner screws.
    [assembly.py, frame.py, params.py]
2026-09-30 fan: largest impeller that fits (Ø26.4, eye 11, 12 radial blades, neck), collet mount
    The motor is speed-limited (18k rpm no-load at 12 V). The study's raised Ø33
    impeller would hit the encoder daughterboards and the raised drive motor, so
    the fan keeps the largest low impeller with the study's small eye, flat
    channel and a neck into the board hole. The body's airbox now presses the
    mount down and clamps the motor through a slotted, tapered collar: two fewer
    screws. LED windows removed (unused on this board).
2026-09-30 board export drops the old wall-sensor casing; detach board children before moving (each copy cloned the whole board)
2026-09-30 wall-sensor caps stand on the footprint outlines and set the LEDs' aim
    Open front at full lens width (the old 3 mm apertures cut ~70 % of the signal),
    crush ribs on each LED's flange and body, a fork around the soldered legs for
    position and yaw, and an emitter_tilt parameter for bench tests. Caps may touch
    the board only inside their outlines (check_layout). Battery rebalanced.
2026-09-30 render: include the fan motor (bought parts); --set overrides parameters for what-if renders; fixed-bore fits allowed in check_layout
    [params.py]
2026-09-30 one-piece bearing blocks, continuous fan legs, flush lid on corner pillars, short cowl, press-fit TPU bumper
    - block: housing and motor seat joined by the hull of both rings, tapering into each
    - fan mount: each leg one profile (deep arm over the impeller, rounded bend into the foot)
    - battery box: rim for a flush lid, screwed into four pillars blended into the corners;
    inner corners tightened so the cells no longer clip them (new check)
    - body: cowl ends just past the fan motor; top flat to the pillars, then the 33 deg plane
    - bumper (TPU) wedges on the board's nose; skirt margin cut back along it
    - show.py sends every part (fan motor, caps, body, lid, bumper)
    [assembly.py, drive.py, fan.py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]
2026-09-30 lid back on top of the walls (level with the nose), held by a nose lip and one rear screw; fan legs rooted high on the collar
    - lid: front edge tucks under a lip on the nose, one M2 at the rear centre (12 screws in total)
    - fan mount legs meet the collar over its full height below the airbox, flared, sloping down to a
    rounded bend into the feet; collet slits moved to 60/180/300 deg, clear of the legs
2026-09-30 fan legs: even taper from collar to foot, straight top and underside slopes (no bump at the root)
2026-09-30 fixes from the design review
    - right rear cap screw was under the pinion, left rear insert cut the sleeve: rear cap screw
    positions are now found per side (clear of the seat bore and the pinion)
    - cap split face relieved 0.15 so tightening clamps bearings and sleeve (fits 0.1)
    - motors 9.61 x 20.3 as measured; glued inserts 3.35 in resin, heat-set 3.1 in PETG
    - hub lip is an open ring outboard of the tire (was a disc closing the drum, inside the tire)
    - magnet cup / hub glued on the axle instead of a press fit in 0.36 mm resin
    - lid: two centre-line screws with 1.5 mm lugs (front lug flush in the nose top), no thin lip;
    inserts 0.8 mm from the cells; rear wing clears the screwdriver
    - so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
    [assembly.py, drive.py, frame.py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]
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2026-09-30 spread the axle bearings with a 0.5 mm housing ridge (magnet gap 1.0 -> 0.5 makes the room)
2026-09-30 drive blocks: no lofts (flat ends, no thin shells), web only under the housing, cap screws clear of the gear
    - the hull of housing and seat spans their overlap; each ring continues on its own with a flat end
    (the lofts left knife-thin shells where the pinion and magnet clearances cut them)
    - the web under the housing no longer extends next to the encoders
    - cap screws at y 15.5: the countersunk heads stay 0.3 clear of the wheel-gear cut-out
    - rear screw placement also keeps the screwdriver clear of the seat ring; pillars start above
    nearby board parts and reach up into a raised ring; the ring-clamp ear stops short of the
    front screw; cap-screw pillars have a 1.0 wall
    [drive.py, params.py]
2026-09-30 smaller nose (just encloses the airbox), third fan-mount leg at the front resting on the MCU
2026-09-30 viewer shows the real populated board (--simple for boxes); sensor-cap fork becomes a U-channel with continuous side walls (no free-standing thin tines)
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2026-09-30 tools/fea.py: structural check of every printed part (gmsh + scikit-fem + pyamg) under crash, drop, spin and clamp loads; body floor bands 9 mm, side strips and a flared left post; collet slits end a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
    [fan.py, frame.py]
2026-09-30 printed stand-in gears (py_gearworks: 7T +0.45 / 36T -0.45 profile shift, pinion tip cut), check_gears.py (mesh sweep, backlash, binding distance, ISO tooth stress), export, layout clearances cover b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
    [assembly.py, gears.py, params.py]
2026-09-30 fix: left block cap was an invalid solid (boss blend coincident with the seat ring; seat re-cut now through); check_layout flags invalid or multi-solid parts; frame.floor() split out; fan.mount allow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
    [drive.py, fan.py, frame.py]
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2026-09-30 structural fixes from fea.py on the open layout: basket with saddle ribs on the caps (no pitching about its two posts), full-height side walls, thicker front/rear wall feet, floor bands along all wal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
    [fan.py, frame.py, params.py]
2026-10-01 low-wall basket with one velcro strap through slotted lugs; feet (two with pegs into cap sockets) replace the saddle ribs; fan mount tabs drop into recessed cap ears; hub tire channel with flanges (n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
    [assembly.py, drive.py, fan.py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]
2026-10-01 print pipeline and four drive variants: one-piece blocks (Layout.blocks = "solid": bearings press in to the ridge, slit clamps on both motor rings) and no-sleeve blocks; block outside drawn the same 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
    [assembly.py, drive.py, ender3v3se.ini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]
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2026-10-05 Second print round: new axle stack, nut fastening, fits at 2.5 s, skids, fan redesign, CFD, sensor caps
    - Axle stack: one-piece wheel (gear, drum, end web) turning round a tube on the base that carries the outer
    bearing inside the wheel (bearings 4.4 mm apart, the wheel grips 2.9 mm of the axle); magnet cup with a long
    sleeve; race spacer and hub gone; bearing pockets for the measured 2.57 mm width; alternative cup for a 4x2 magnet
    - Fastening: board screws into M2 nuts 0.9 mm above the board (side slots), ring clamps into trapped nuts,
    deeper cap-screw insert pockets; fan clamp ears tall enough to enclose the nut; fan mount without the front leg
    - Fits from the 2.0 s / 2.5 s prints an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
    [assembly.py, drive.py, fan.py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]
2026-10-05 Thin motor rings, longer grip, Ø4 magnet default, radial fan default
    - Eccentric sleeves dropped (drive variants: drive_split, drive_solid); the motor rings are drawn for the motor:
    1.5 mm wall, centred on it (2.1-2.7 mm when drawn for the sleeves), so the battery tray sits 1 mm lower (28.0)
    - Rings run inboard to 1 mm short of the centre line (14 mm of grip, was 7.4), slotted from below round the
    encoder boards; the motor's front face stops on a 1 mm flat ledge before the 50 deg cone
    - Right frame boss blended into its ring from the ring's inboard end (it stood clear of the thin ring and would
    start in mid-air as the cap prints)
    - Ø4x2 magnet is the default cup; the Ø6x2 cup (magne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
    [assembly.py, drive.py, fan.py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]
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2026-10-05 Remove the previous design's SolidWorks/STEP/DXF files (in the history: git show 1307880:MicrasAssembly.STEP) and the unused slicing profiles (flat.ini, resin_standard.ini)
    [Base.SLDPRT, Base.STEP, Battery.SLDPRT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]
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2026-10-05 Fasteners in the model (fasteners.py): the M2 screws, nuts and inserts placed from the helpers that cut their holes, in the viewer, STEP and mass report; check_layout lets them touch only their hosts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
    [assembly.py, drive.py, mass.py]
2026-10-05 Clamp screws closer to their motors; clean cap screw heads, peg sockets and frame boss
    - Ring clamp screw 1.1 mm closer to the upper motor (0.6 mm of resin between its nut trap and the bore; the trap
    runs on down through the ring's outside), moved inboard to y 8.9 so the nut goes in from below clear of the
    housing; fan clamp screw 0.5 mm closer (the ears end the same 2.6 past it)
    - Cap screw heads: the clearance opens out through the outer face (a 0.25 mm skin over each head broke into points
    and fins), cut as one slot shape and again after the boss's blend; the rear screws moved back so it stays 0.3
    off the motor rings
    - A screw column joins the raised ring only where they overlap b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
    [drive.py, fan.py]
2026-10-07 Brass gears, one-piece blocks by default, PLA sensor caps
    - Brass gears (Gears.wheel_gear = "brass", the default): the motors carry the
    bought 7T pinions (no printed pinions); the bought 36T is drilled in a printed
    guide (gear_guide.py: square for a vise, a pocket with the gear's tooth
    outline, a square lid with the drill holes; bore to Ø7.8, three Ø2.2 holes on
    Ø12.3, countersunk) and screwed to the printed wheel with three M2x5 flat
    heads into nuts in hex pockets on the wheel's outer face. The drum stays
    hollow: the gear sits only on the three nut columns. The printed-gear wheel is
    an alternative (it runs with the brass pinion at about 0.25 mm of backlash).
    - Printed gear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
    [assembly.py, drive.py, fit_test.py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]
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2026-10-11 Plain-shaft impeller by default; fan motor in from below onto snap bumps; stronger wheel axle boss
    - Params.fan_motor is the Ø1.5 x 6 shaft motor; the impeller's round blind bore (1.52, a press) is the default,
    the shaft's end bottoms in it (FanParams.bore = "pinion" keeps the 9T-pinion bore)
    - fan mount: the collar's bore runs straight through (the impeller is glued on for good, so the motor goes in
    from below), 0.15 over the can, with four small bumps at its foot that snap in under the motor's face and set
    its height; sliced and checked: no supports reach them
    - wheel: the axle boss flares from Ø4 to Ø8 onto a 1.2 mm end web (was a straight Ø4 boss on 0.8)
    - trials plate: the imp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
2026-10-11 Every wheel numbered with its backlash; round 9 trials plate
    - drive.wheel engraves each printed-gear wheel's design backlash with the brass pinion, in hundredths, on the
    gear's inboard face (gears.brass_pinion_backlash; the robot's wheels: "25")
    - trials plate: the robot's drive blocks, two fan mounts and two impellers, and wheel pairs with 0.20, 0.24 and
    0.28 mm of backlash (unshifted 36T); the tire cutting guide moves to alternatives
